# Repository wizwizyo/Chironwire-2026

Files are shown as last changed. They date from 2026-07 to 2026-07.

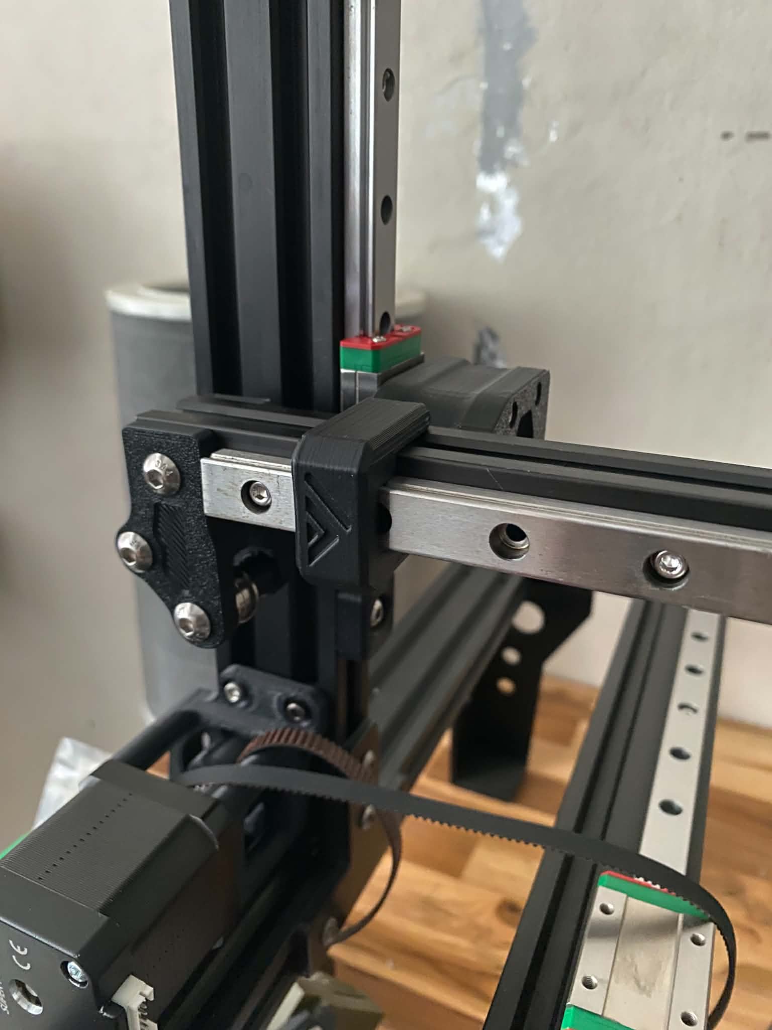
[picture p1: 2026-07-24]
png/5e9dcb9d-3fec-4d9b-b8f9-6c0ed09c6b4d.jpg

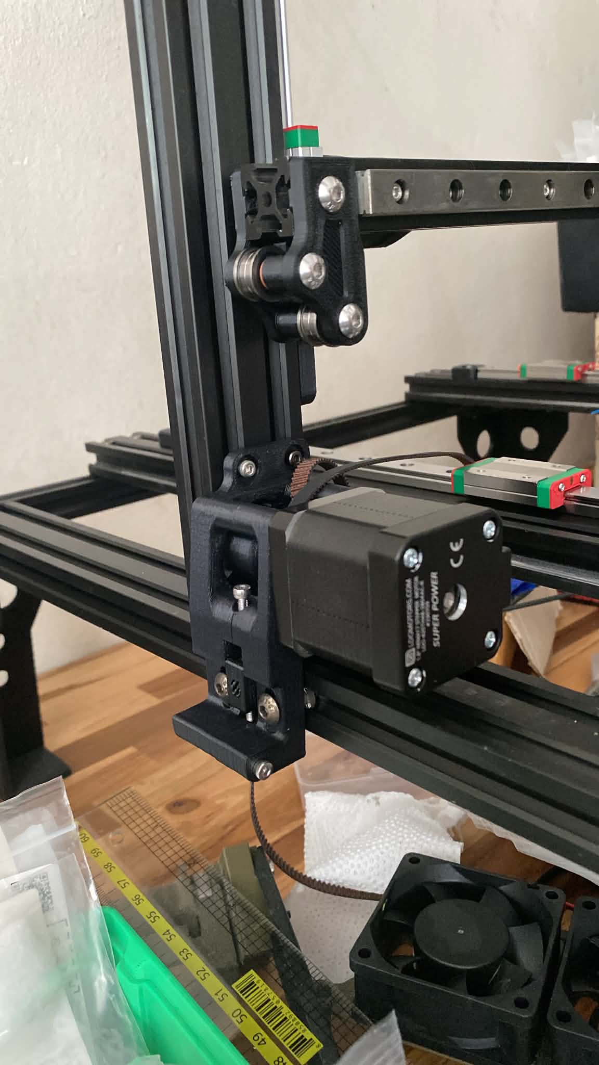
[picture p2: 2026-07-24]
png/1693ed17-f3ee-4091-8e09-6b01db80949f.jpg

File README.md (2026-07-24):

**Chironwire 2026**

** Update Version 2026 ** Redesigned this section to address the following issues:

- Parts did not fit flush when assembled into the frame.
- The motor mount would flex under high acceleration.
- Added a support bearing to reduce the risk of motor shaft misalignment caused by excessive belt tension.



** Disassembly and assembly steps **
- remove all existing electronics
- remove the bed

- install linear guide with **MGN12H_2040_Guide.stl**
Front view: This is the spacing between the linear rail and the guard as designed
4da12b11-4b8c-405c-b23f-5e3c2b48af57|
- connect the 3 pieces composing the Y carriage frame using the leftover 8mm spacers

**MGN12 Drilling Y A-xis guide**

- Use MGN12H_(M3_20x20mm)_Y_AXIS.stl the mounting hole spacing is designed for M3 screws with a 20 × 20 mm pattern. Please measure your linear rail before installation, as the hole spacing may vary between manufacturers. However, this is not a major issue , you can simply drill the holes out to 4 mm to provide enough clearance.
280f26b1-d70f-42f9-9b4a-be8f6eb953e4

I used a spring plunger

cdc93a92-7736-4de8-8f81-1e79ead178e7
280f26b1-d70f-42f9-9b4a-be8f6eb953e4

- Install the assembly onto the Y-axis linear rail.
If the bed feels stiff or does not move smoothly after installation, slightly loosen the linear rail mounting screws. Move the bed back and forth to allow the rail to self-align. For example, with the bed at the front, tighten one M3 screw. Then move the bed to the rear and tighten the next M3 screw. Repeat this process until the bed moves smoothly, then fully tighten all of the screws.** This will not cause any issues, as the Y-axis is not part of a CoreXY printer.**

b8ede8ee-4f5d-4bcb-b8b6-78630baa8b45

XZ Motor 

- Install the 625 bearings. You can reuse the two 625 bearings from the V-wheels that were removed.
- Assemble it according to the original Switchwire assembly guide. The only additional hardware required is:
M3×25 screw
M3×8 screw
M3×5×4 heat-set insert nut

6fcd44f3-0f03-40ae-b3f3-7f80906ff85a

9d3b7f99-f0ae-4429-afc5-b46df814d016
7e8b8b0d-8bbf-4f2e-a519-91bd42f692cd

- From this point onward, the build is almost identical to the original Switchwire. You can continue by following the official Switchwire assembly guide.**
https://github.com/VoronDesign/Voron-Switchwire/blob/master/Manuals/Assembly_Manual_SW.pdf

5e9dcb9d-3fec-4d9b-b8f9-6c0ed09c6b4d

For the wiring, if you're using the same control board as I am, you can follow the wiring example shown below.

Thanks for credit and edit from

- https://github.com/Jamiever6/ChironWire/tree/main
- https://github.com/VoronDesign/Voron-Switchwire/tree/master

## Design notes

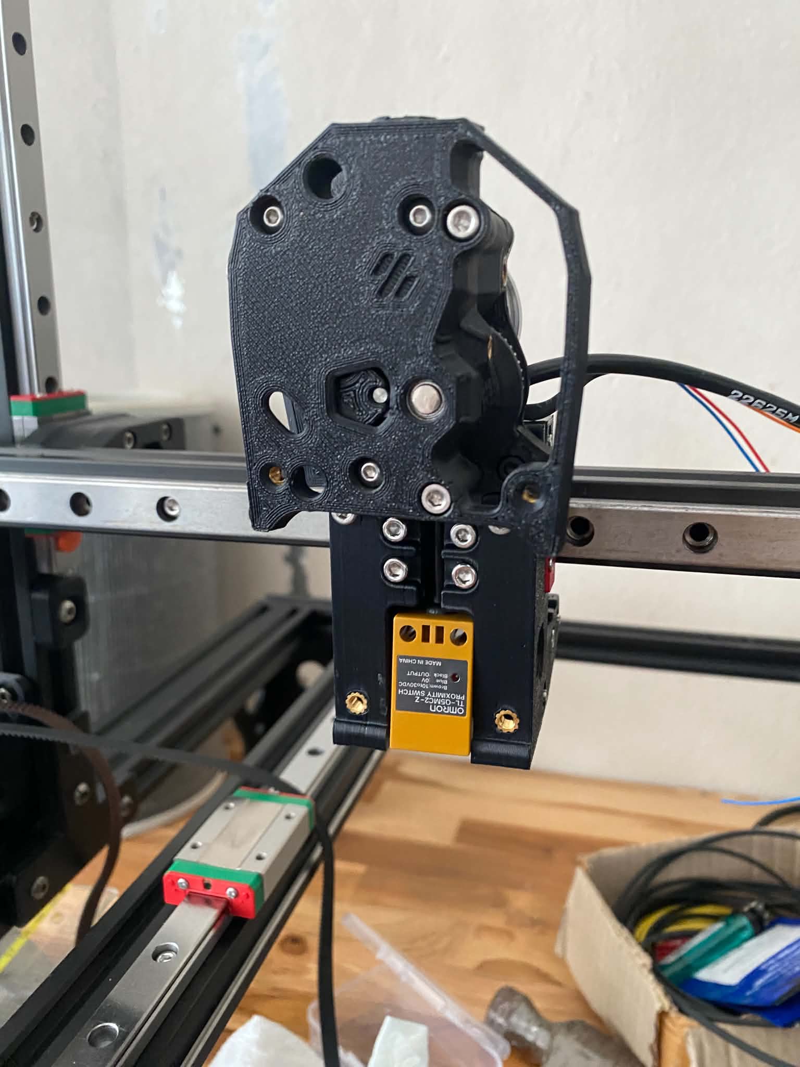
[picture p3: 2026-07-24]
png/90c42b49-2de0-41a4-be3c-570cbc608be3.jpg

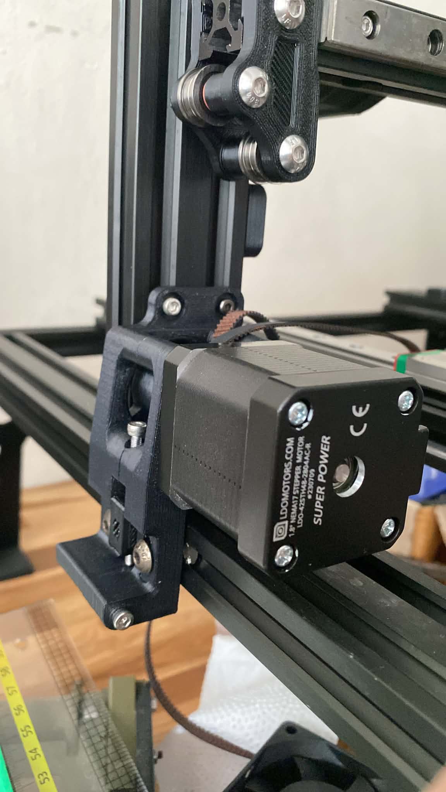
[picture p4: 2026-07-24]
png/7e8b8b0d-8bbf-4f2e-a519-91bd42f692cd.jpg

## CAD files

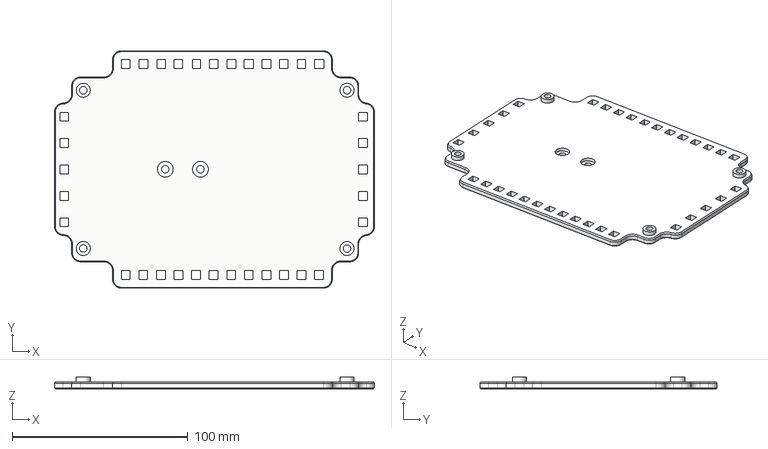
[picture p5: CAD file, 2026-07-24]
STEP/Electronic/BTT_Octopus_holder.step
182.0 x 135.0 x 6.60 mm

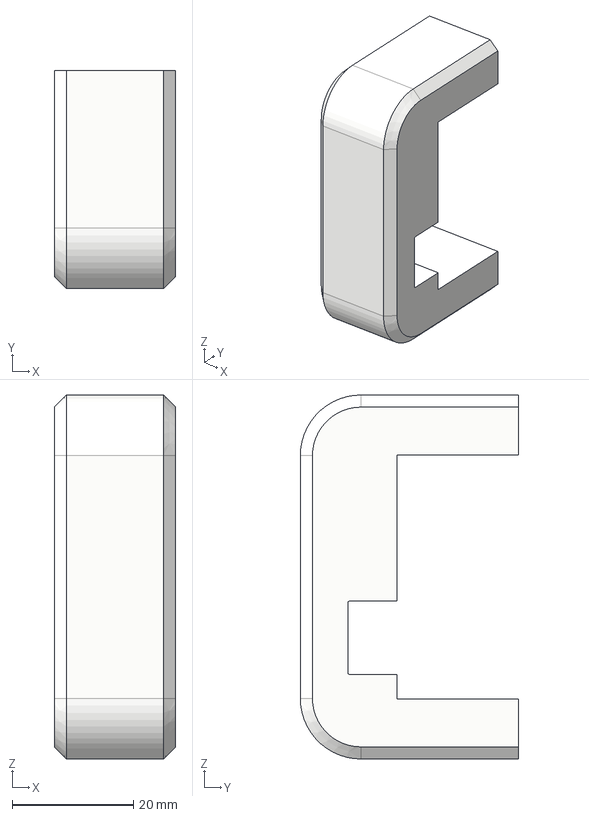
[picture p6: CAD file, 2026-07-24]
STEP/Linear Rail guide/MGN12H_2040_Guide.step
20.0 x 36.0 x 60.0 mm

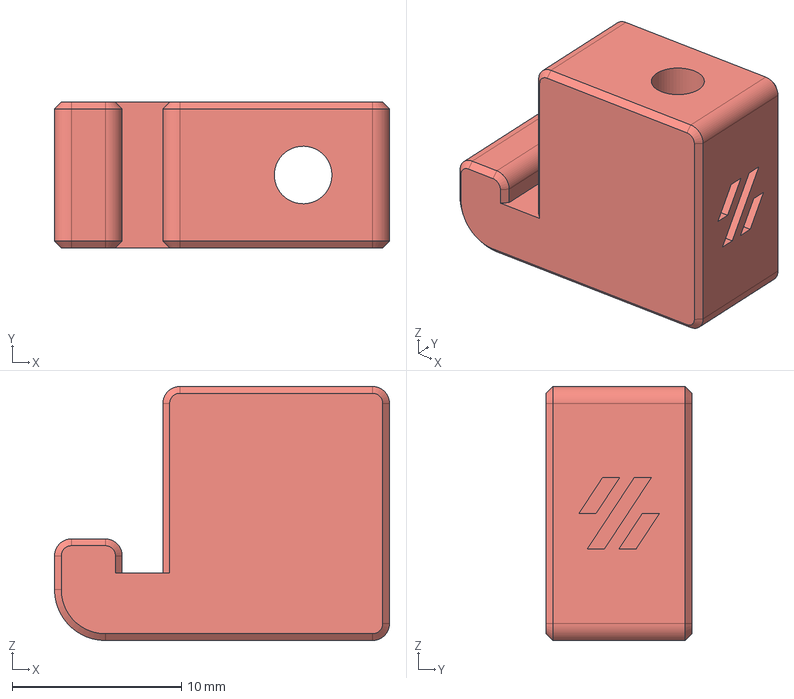
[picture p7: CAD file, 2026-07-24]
STEP/x2 Tensioner.step
19.8 x 8.60 x 15.0 mm

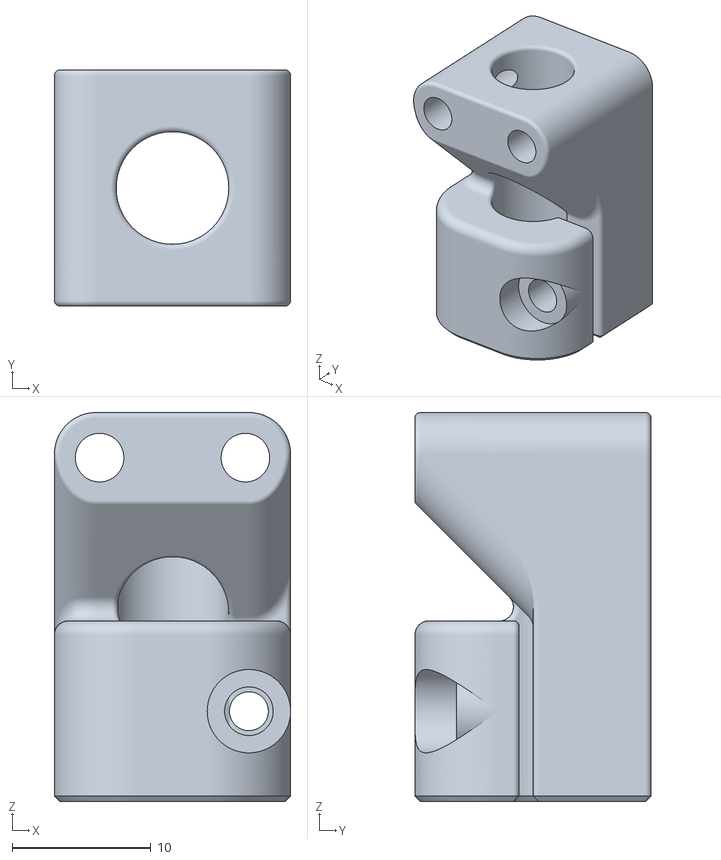
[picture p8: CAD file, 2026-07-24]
STL/Gantry/X_Carriage/pinion.stl
17.0 x 17.0 x 28.0

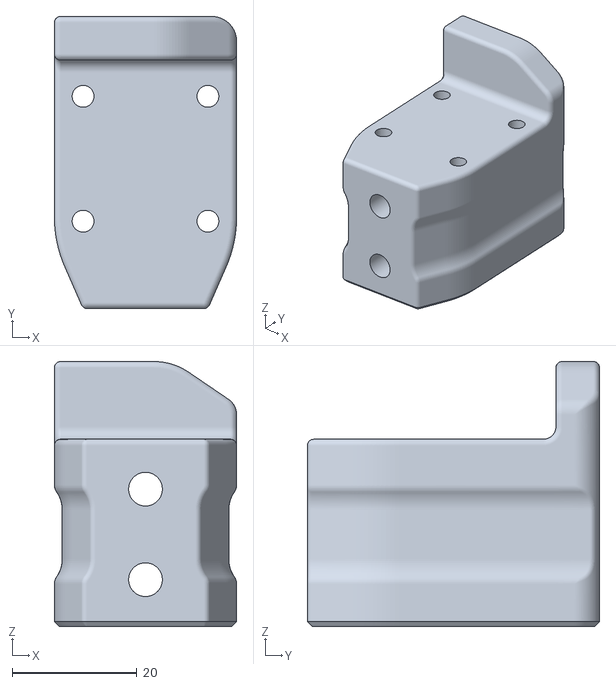
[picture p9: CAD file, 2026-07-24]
STL/Gantry/z_bearing_block_right_generic.stl
29.2 x 46.8 x 42.4

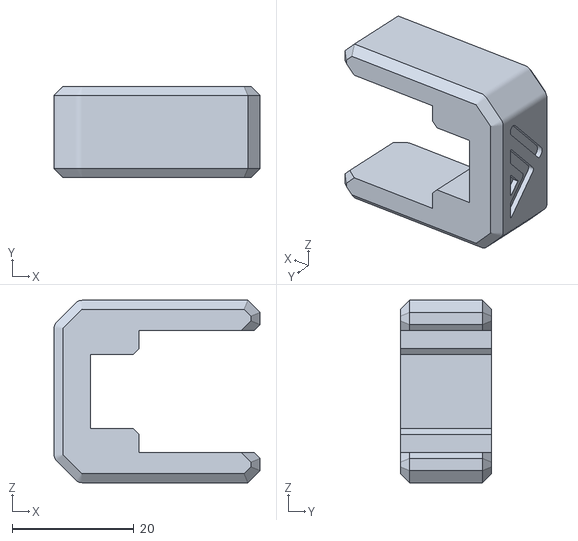
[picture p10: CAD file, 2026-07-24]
STL/Linear Rail guide/mgn12 allignment tool.stl
33.9 x 15.0 x 30.0

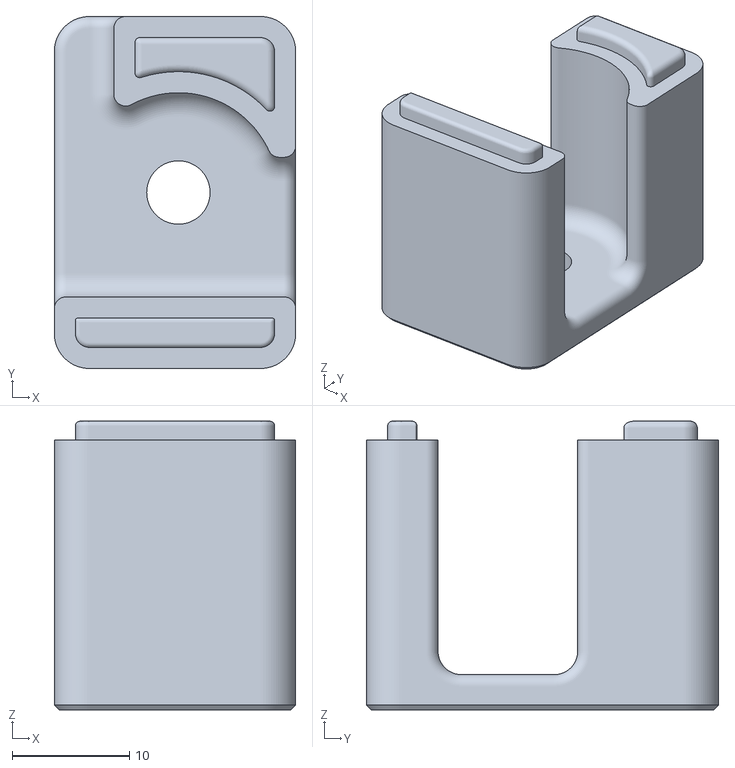
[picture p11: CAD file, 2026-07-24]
STL/upper_idler_support_a_left.stl
20.6 x 30.0 x 24.6

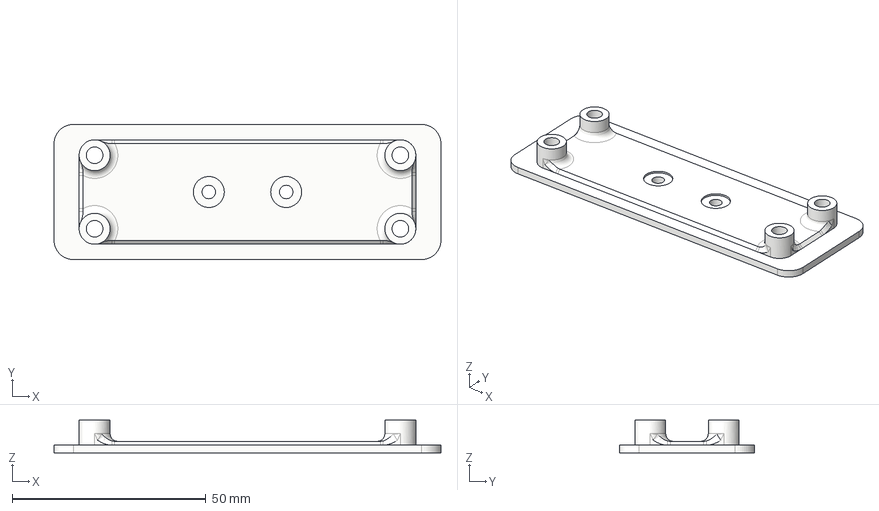
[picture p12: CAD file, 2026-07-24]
STEP/Electronic/BTT_U2C_Holder.step
100.0 x 34.9 x 8.50 mm

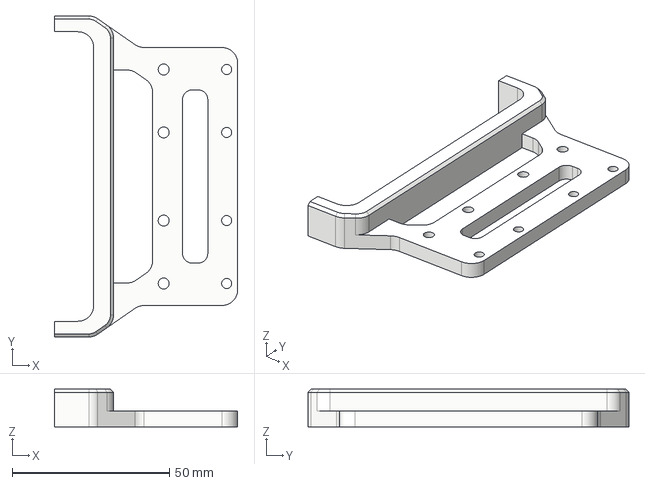
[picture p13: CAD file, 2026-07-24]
STEP/Linear Rail guide/MGN12H_M3(20x20mm)_Y_AXIS.step
58.2 x 102.0 x 12.0 mm

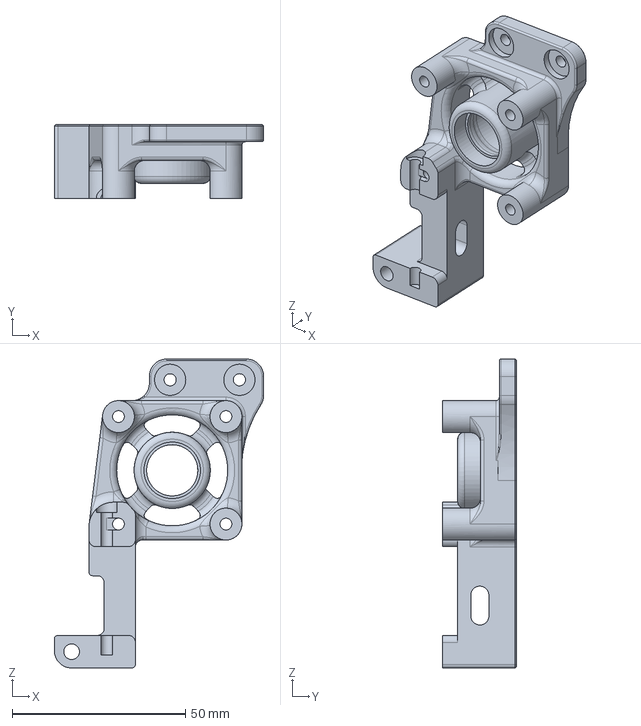
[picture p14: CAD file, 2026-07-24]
STEP/x_motor_mount_a.step
60.4 x 21.4 x 89.1 mm
Z Motor
X Motor

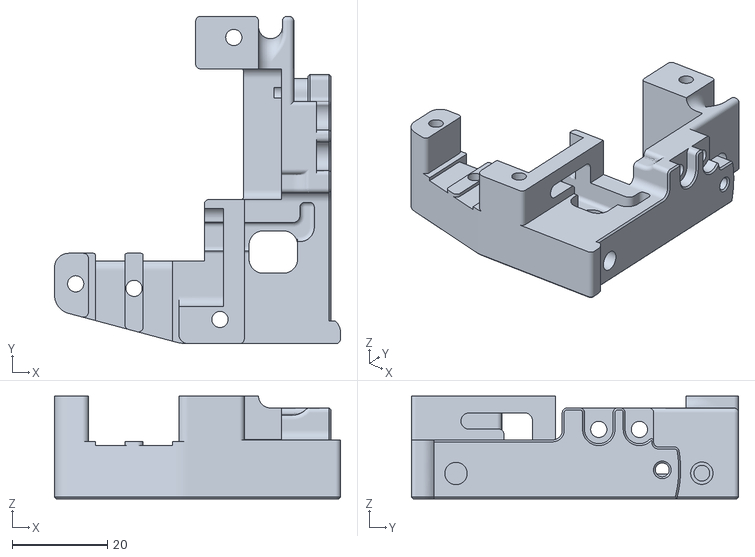
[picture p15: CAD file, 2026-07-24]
STL/Gantry/X_Carriage/x_frame_SW_right.stl
60.0 x 68.8 x 21.6

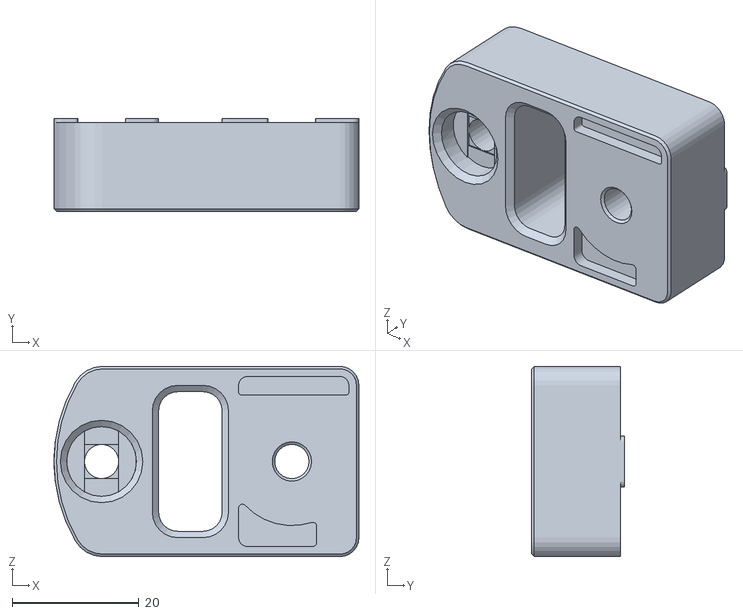
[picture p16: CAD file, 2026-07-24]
STL/Switchwire_Upper block right_Chiron_v1.stl
48.1 x 14.6 x 30.0

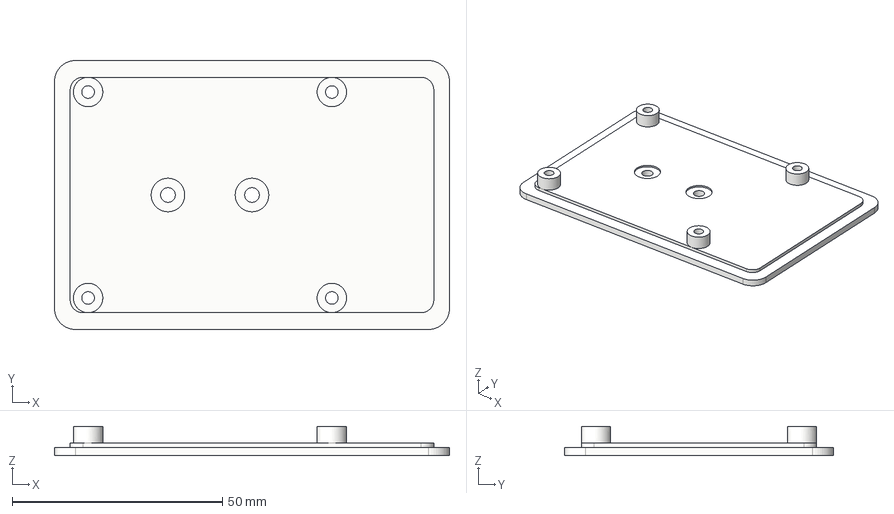
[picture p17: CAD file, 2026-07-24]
STEP/Electronic/Raspi3b+_Holder.step
94.0 x 64.0 x 7.00 mm

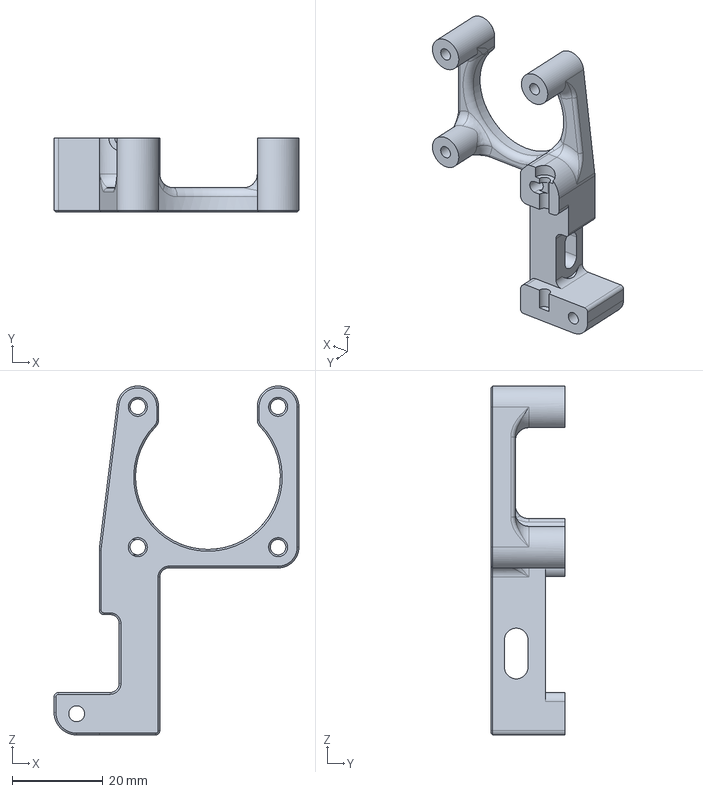
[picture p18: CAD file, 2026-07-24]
STEP/x_motor_mount_b.step
54.1 x 16.4 x 77.1 mm
Z Motor
X Motor

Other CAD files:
STL/Gantry/z_bearing_block_right_igus.stl
STL/Gantry/X_Carriage/[a]_xz_belt_clip_x2.stl
STL/Gantry/z_bearing_block_left.stl
STL/Switchwire_upper block left_Chiron_v1.stl
STEP/Electronic/BED_MOSFET_holder.step
STEP/z_motor_mount_a.step
STEP/z_motor_mount_b.step
STL/Electronic/BED_MOSFET_holder.stl
STL/Electronic/BTT_Octopus_holder.stl
STL/Electronic/BTT_U2C_Holder.stl
STL/Electronic/Raspi3b+_Holder.stl
STL/Gantry/X_Carriage/[a]_x_bearing_block.stl
STL/Gantry/X_Carriage/probe_retainer_bracket.stl
STL/Gantry/X_Carriage/x_frame_SW_left.stl
STL/Linear Rail guide/MGN12H_(M3_20x20mm)_Y_AXIS.stl
STL/Linear Rail guide/MGN12H_2040_Guide.stl
STL/upper_idler_support_a_right.stl
STL/x2 Tensioner.stl
STL/x_motor_mount_a.stl
STL/x_motor_mount_b.stl
STL/xz_block_left_a.stl
STL/xz_block_left_b.stl
STL/xz_block_right_a.stl
STL/xz_block_right_b.stl
STL/z_motor_mount_a.stl
STL/z_motor_mount_b.stl

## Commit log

2026-07-20 Create STL
2026-07-24 Update README with additional images
    Added new images to the assembly guide section.
2026-07-24 Update README with Switchwire assembly guide link
    Added a link to the official Switchwire assembly guide.
